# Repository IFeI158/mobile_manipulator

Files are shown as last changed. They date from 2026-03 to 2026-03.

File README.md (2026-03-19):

# Mobile Manipulator Robot (지능형 도우미 로봇)

거동이 불편한 사용자가 원격으로 물체를 지정하면, 지능형 도우미 로봇이 해당 물체를 스스로 찾아 집어 가져오는 시스템입니다.

모바일 플랫폼(TurtleBot3)과 직접 설계·제작한 4-DOF 로봇팔을 결합한 **Mobile Manipulator** 로, ArUco 마커 기반 비전과 역기구학(IK)을 통해 물체를 자율적으로 집어 초기 위치로 복귀합니다.

---

## Project Overview

| 항목 | 내용 |
|---|---|
| 기간 | 2025.03 – 2025.06 (1학기 캡스톤 디자인) |
| 인원 | 5명 |
| 역할 | Hardware 설계 / Vision 개발 |
| 플랫폼 | TurtleBot3 Burger + 직접 제작 로봇팔 |

---

## System Architecture

```
User ('p' key press)
        ↓
OAK-D Camera — ArUco Marker Detection
        ↓
3D Position Estimation (Stereo Depth + IQR Filter)
        ↓
Inverse Kinematics (ik_solver.py)
        ↓
Serial Command → Arduino (amurokena.ino)
        ↓
Servo Motion → Pick Object → Return to Home
```

---

## Repository Structure

```
mobile-manipulator/
├── vision/
│   ├── aruco_vision.py        ArUco 인식 + 3D 좌표 추출 (디버깅용)
│   └── color_vision.py        HSV 색상 인식 초기 버전 (참고용)
│
├── arm_control/
│   ├── main.py                메인 실행 파일 (ArUco + IK + 시리얼 통합)
│   ├── ik_solver.py           역기구학 계산 모듈
│   └── test_ik.py             터미널 수동 테스트용
│
├── arduino/
│   ├── amurokena/
│   │   └── amurokena.ino      최종 Arduino (moveAllSmooth + 자동 파지/복귀)
│   └── slow/
│       └── slow.ino           이전 버전 Arduino (참고용)
│
├── ros2_ws/
│   └── src/
│       ├── capstone_design_description/   URDF + STL 메시
│       └── capstone_design_config/        MoveIt2 설정
│
├── robotarm_capstone.xacro    로봇팔 XACRO 모델
└── README.md
```

---

## Hardware

| 부품 | 사양 |
|---|---|
| Mobile Platform | TurtleBot3 Burger |
| Controller | OpenCR 1.0 |
| Camera | Luxonis OAK-D (DepthAI) |
| LiDAR | YDLiDAR |
| Servo ×6 | MG996R / SG90 |
| MCU | Arduino Uno |

### Robot Arm Link Parameters

| Link | Length | Description |
|---|---|---|
| L1 | 20.404 cm | Shoulder → Elbow |
| L2 | 17.617 cm | Elbow → Wrist |
| L3 | 4.65 cm | Wrist → End-effector |
| BASE_Z_OFFSET | 7.8 cm | Base → first joint height |

### Arduino Pin Mapping

| Servo | Pin | Role |
|---|-----|---|
| servo0 | 12 | BASE yaw |
| servo1a | 11 | SHOULDER (forward) |
| servo1b | 10 | SHOULDER (reverse, 180 − s1) |
| servo2 | 9 | ELBOW |
| servo3 | 8 | WRIST |
| servo4 | 7 | GRIPPER |

---

## Software Stack

- **ROS2 (Humble)** — Navigation, TF, SLAM
- **Python 3** — Vision, IK, serial communication
- **DepthAI** — OAK-D stereo depth pipeline
- **OpenCV** — ArUco detection
- **Arduino** — Servo control

---

## Quick Start

### 1. Install dependencies

```bash
pip install depthai opencv-python numpy pyserial
```

### 2. Upload Arduino firmware

Open `arduino/amurokena/amurokena.ino` in Arduino IDE and upload to Arduino Uno.

### 3. Run main program

```bash
cd arm_control
python3 main.py
```

### 4. Key controls

| Key | Action |
|-----|---|
| `p` | Move arm to ArUco ID 9 marker position |
| `o` | Print ArUco ID 10 coordinates (debug) |
| `q` | Quit |

### 5. Manual IK test (without camera)

```bash
cd arm_control
python3 test_ik.py
# > 10 0 -5    (x y z in cm, camera frame)
```

---

## Serial Protocol

```
Python → Arduino : "s0,s1,s2,s3\n"         (4 angles, comma-separated)
Arduino → Python : "Received: s0,s1,s2,s3"  (debug echo)
Arduino → Python : "done"                    (pick-and-return complete)

Port  : /dev/ttyACM0
Baud  : 9600
```

---

## ArUco Marker IDs

| ID | Role |
|----|---|
| 9 | Target object — arm moves here on `p` key |
| 10 | Drop zone — coordinates printed on `o` key |

Dictionary: `DICT_4X4_50`

---

## Demonstration

> 시연 영상 추가 예정

---

## Future Improvements

- `hujin.py` — 물체 파지 후 Nav2를 통한 후진 복귀 로직 구현
- Object detection 기반 자동 마커 없는 물체 인식
- MoveIt2 기반 Motion Planning 통합
- SLAM 환경 인식 개선

---

## Author

**IFeI158** — Mechanical Engineering / Robotics & Autonomous Systems

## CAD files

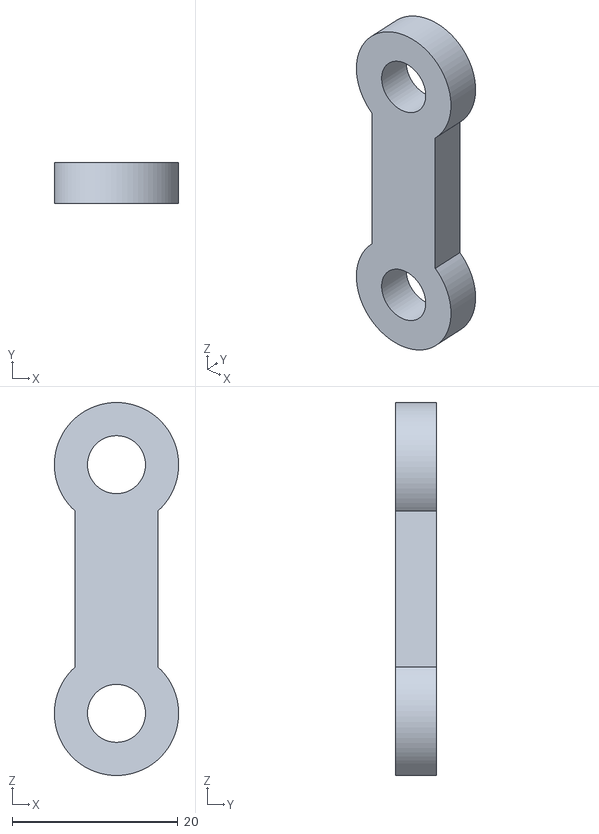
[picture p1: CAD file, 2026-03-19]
ros2_ws/src/capstone_design_description/meshes/left_gripper_link_1.stl
15.0 x 5.00 x 45.0

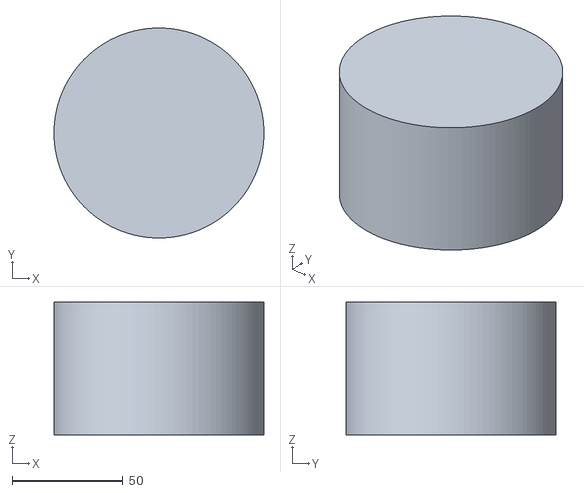
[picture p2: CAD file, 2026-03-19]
ros2_ws/src/capstone_design_description/meshes/lidar_1.stl
95.0 x 95.0 x 60.0

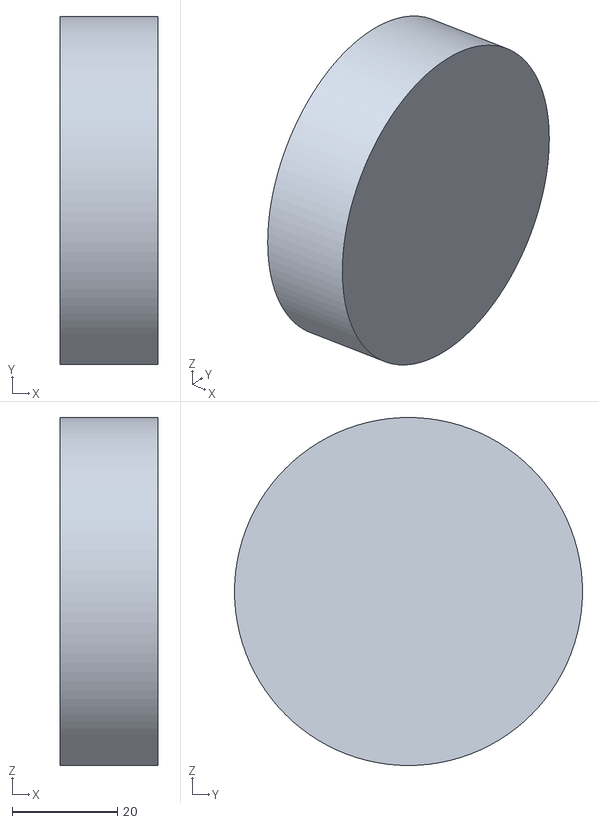
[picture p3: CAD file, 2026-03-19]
ros2_ws/src/capstone_design_description/meshes/right_wheel_1.stl
18.6 x 66.0 x 66.0

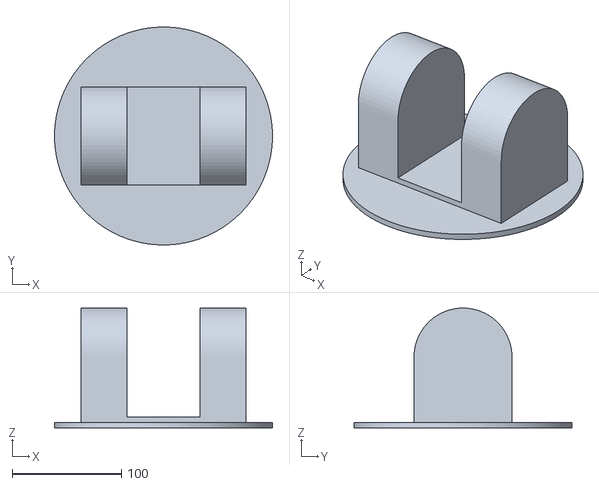
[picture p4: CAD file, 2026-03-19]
ros2_ws/src/capstone_design_description/meshes/link1_1.stl
200.0 x 199.9 x 110.0

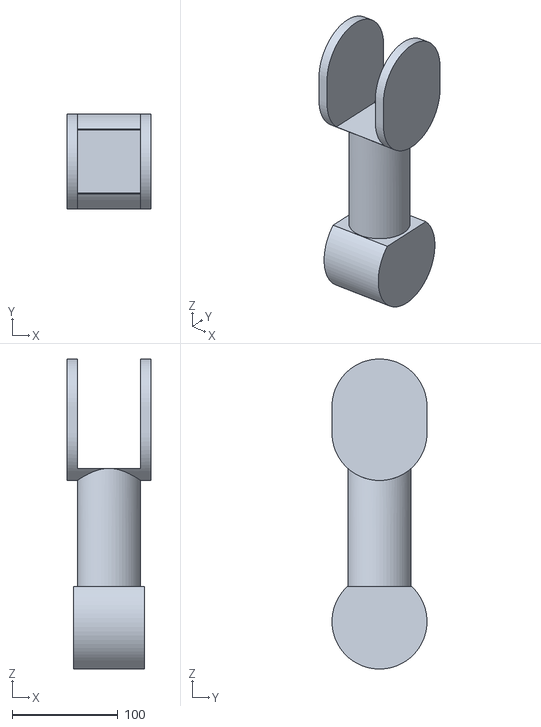
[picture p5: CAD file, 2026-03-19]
ros2_ws/src/capstone_design_description/meshes/link2_1.stl
80.0 x 90.0 x 293.5

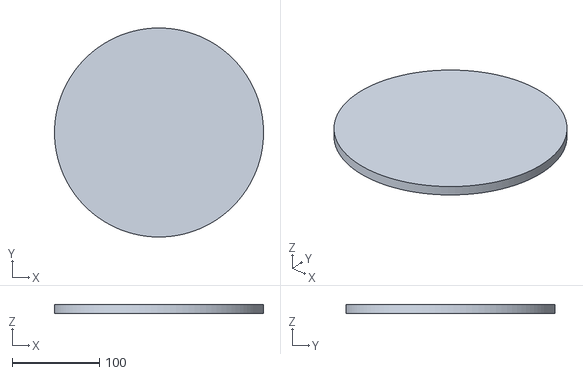
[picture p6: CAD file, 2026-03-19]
ros2_ws/src/capstone_design_description/meshes/arm_base_link_1.stl
239.9 x 240.0 x 10.0

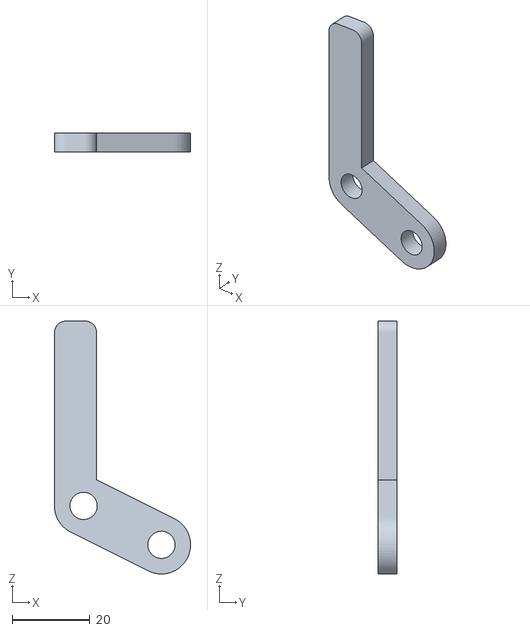
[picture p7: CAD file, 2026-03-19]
ros2_ws/src/capstone_design_description/meshes/right_finger_1.stl
35.0 x 5.00 x 65.0

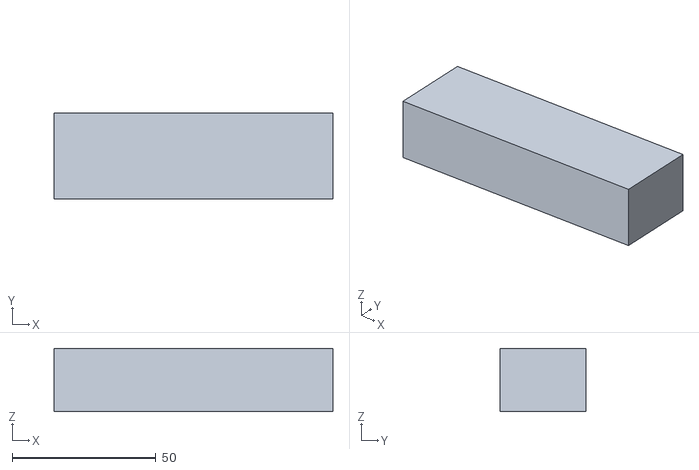
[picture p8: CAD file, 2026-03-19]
ros2_ws/src/capstone_design_description/meshes/stereo_camera_1.stl
97.0 x 30.0 x 22.0

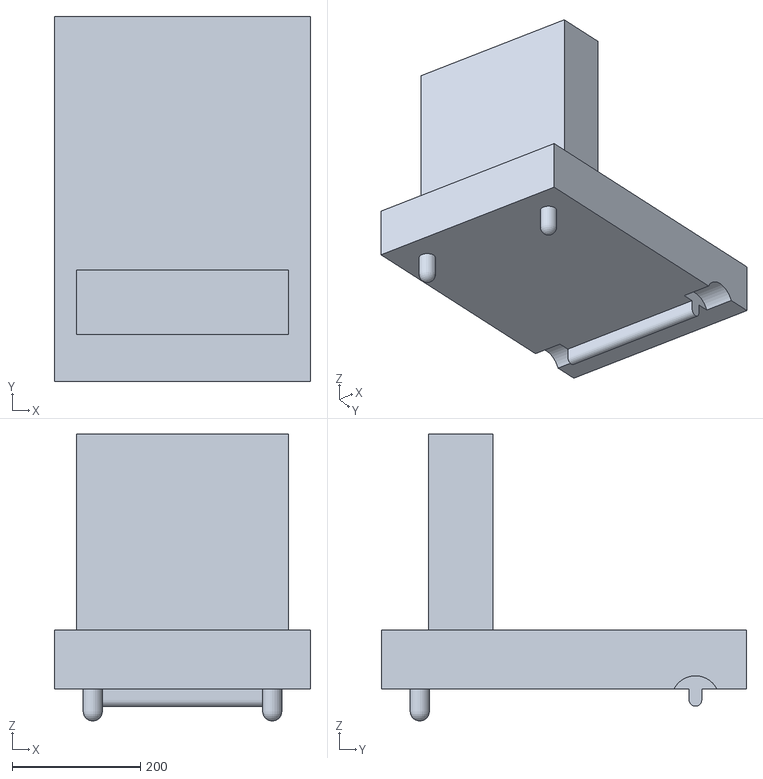
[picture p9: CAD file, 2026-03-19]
ros2_ws/src/capstone_design_description/meshes/base_link.stl
400.0 x 570.0 x 447.7

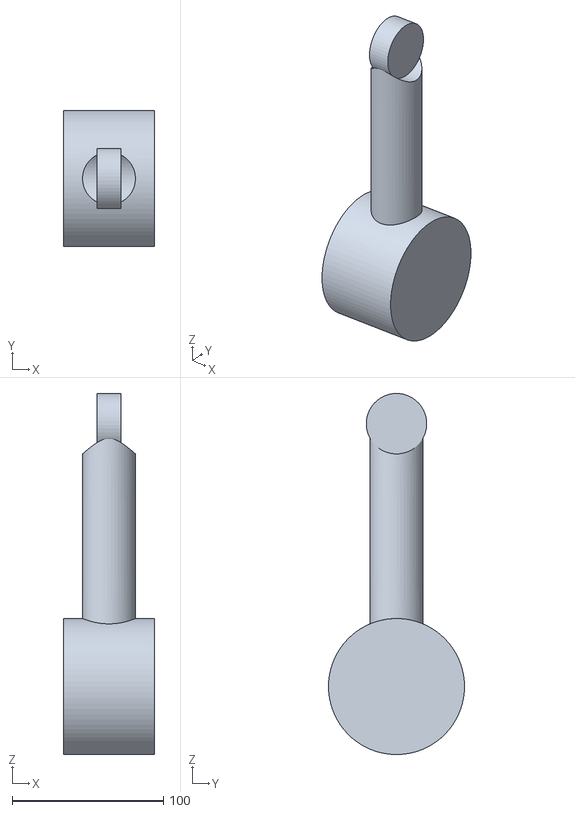
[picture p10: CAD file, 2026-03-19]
ros2_ws/src/capstone_design_description/meshes/link3_1.stl
60.0 x 90.0 x 238.8

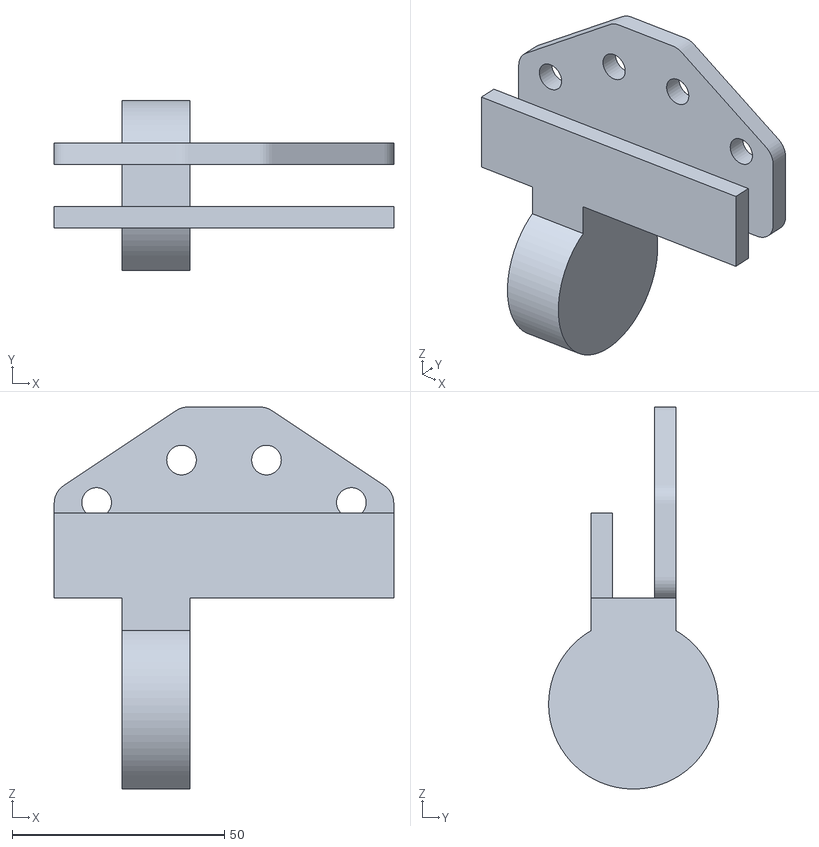
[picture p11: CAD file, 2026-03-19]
ros2_ws/src/capstone_design_description/meshes/hand_link_1.stl
80.0 x 40.0 x 90.0

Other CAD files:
ros2_ws/src/capstone_design_description/meshes/right_gripper_link_1.stl
ros2_ws/src/capstone_design_description/meshes/left_wheel_1.stl
ros2_ws/src/capstone_design_description/meshes/left_finger_1.stl

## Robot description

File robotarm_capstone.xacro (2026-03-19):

<?xml version="1.0" ?>
<robot name="robotarm_capstone" xmlns:xacro="http://www.ros.org/wiki/xacro">

<xacro:include filename="$(find robotarm_capstone_description)/urdf/materials.xacro" />
<xacro:include filename="$(find robotarm_capstone_description)/urdf/robotarm_capstone.trans" />
<xacro:include filename="$(find robotarm_capstone_description)/urdf/robotarm_capstone.gazebo" />
<link name="base_link">
  <inertial>
    <origin xyz="4.020849375084743e-17 0.0 0.005000000000000001" rpy="0 0 0"/>
    <mass value="3.551256335617901"/>
    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
  </inertial>
  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
</link>

<link name="link1_1">
  <inertial>
    <origin xyz="2.0030450291854913e-17 2.0030450291854907e-17 0.04290880959465924" rpy="0 0 0"/>
    <mass value="7.128679889758317"/>
    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
  </inertial>
  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
</link>

<link name="link2_1">
  <inertial>
    <origin xyz="0.03360000772838613 -8.485027970501936e-11 0.06805286707917997" rpy="0 0 0"/>
    <mass value="6.954595389355063"/>
    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
  </inertial>
  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
</link>

<link name="link3_1">
  <inertial>
    <origin xyz="0.030000023541393757 4.114813245135107e-18 0.02802505675959771" rpy="0 0 0"/>
    <mass value="3.999606826289236"/>
    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
  </inertial>
  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
</link>

<link name="hand_link_1">
  <inertial>
    <origin xyz="-0.0017307714096714746 0.0029387009017803663 0.018364409381455116" rpy="0 0 0"/>
    <mass value="0.28375707869235817"/>
    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
  </inertial>
  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
</link>

<link name="right_gripper_link1_1">
  <inertial>
    <origin xyz="-6.42194630806614e-14 -0.002499999999999998 0.014999999999971148" rpy="0 0 0"/>
    <mass value="0.01720971564055042"/>
    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
  </inertial>
  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
</link>

<link name="right_gripper_link2_1">
  <inertial>
    <origin xyz="-6.4248953379753e-14 -0.002499999999999998 0.014999999999971148" rpy="0 0 0"/>
    <mass value="0.017209715640550204"/>
    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
  </inertial>
  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
</link>

<link name="left_gripper_link2_1">
  <inertial>
    <origin xyz="-6.424548393280105e-14 -0.002499999999999998 0.014999999999971037" rpy="0 0 0"/>
    <mass value="0.0172097156405502"/>
    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
  </inertial>
  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
</link>

<link name="left_gripper_link1_1">
  <inertial>
    <origin xyz="-6.42715047849407e-14 -0.002499999999999998 0.014999999999970925" rpy="0 0 0"/>
    <mass value="0.01720971564055051"/>
    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
  </inertial>
  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
</link>

<link name="right_finger_1">
  <inertial>
    <origin xyz="-0.0038609530597631878 -0.002499999999999998 0.010996703413204356" rpy="0 0 0"/>
    <mass value="0.03447696599229279"/>
    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
  </inertial>
  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
</link>

<link name="left_finger_1">
  <inertial>
    <origin xyz="-0.01613904694030094 -0.002499999999999998 0.020996703413204365" rpy="0 0 0"/>
    <mass value="0.034476965992292836"/>
    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
  </inertial>
  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
</link>

<joint name="base_link_to_link1" type="revolute">
  <origin xyz="0.0 0.0 0.01" rpy="0 0 0"/>
  <parent link="base_link"/>
  <child link="link1_1"/>
  <axis xyz="0.0 0.0 1.0"/>
  <limit upper="1.570796" lower="-1.570796" effort="100" velocity="100"/>
</joint>

<joint name="link1_to_link2" type="revolute">
  <origin xyz="-0.0336 0.0 0.065" rpy="0 0 0"/>
  <parent link="link1_1"/>
  <child link="link2_1"/>
  <axis xyz="-1.0 0.0 0.0"/>
  <limit upper="1.570796" lower="-1.570796" effort="100" velocity="100"/>
</joint>

<joint name="link2_to_link3" type="revolute">
  <origin xyz="0.0036 0.0 0.203557" rpy="0 0 0"/>
  <parent link="link2_1"/>
  <child link="link3_1"/>
  <axis xyz="-1.0 0.0 0.0"/>
  <limit upper="1.570796" lower="-1.570796" effort="100" velocity="100"/>
</joint>

<joint name="link3_to_hand_link" type="revolute">
  <origin xyz="0.022 0.0 0.1739" rpy="0 0 0"/>
  <parent link="link3_1"/>
  <child link="hand_link_1"/>
  <axis xyz="-1.0 0.0 0.0"/>
  <limit upper="1.570796" lower="-1.570796" effort="100" velocity="100"/>
</joint>

<joint name="hand_link_to_left_gripper_link2" type="revolute">
  <origin xyz="0.018 0.005 0.0575" rpy="0 0 0"/>
  <parent link="hand_link_1"/>
  <child link="left_gripper_link2_1"/>
  <axis xyz="0.0 1.0 -0.0"/>
  <limit upper="1.22173" lower="0.0" effort="100" velocity="100"/>
</joint>

<joint name="hand_link_to_left_gripper_link1" type="revolute">
  <origin xyz="0.038 0.005 0.0475" rpy="0 0 0"/>
  <parent link="hand_link_1"/>
  <child link="left_gripper_link1_1"/>
  <axis xyz="0.0 1.0 -0.0"/>
  <mimic joint="hand_link_to_left_gripper_link2" multiplier="1.0" offset="0.0"/>
  <limit upper="1.22173" lower="0.0" effort="100" velocity="100"/>
</joint>

<joint name="left_gripper_link1_to_left_finger" type="revolute">
  <origin xyz="0.0 -0.005 0.03" rpy="0 0 0"/>
  <parent link="left_gripper_link1_1"/>
  <child link="left_finger_1"/>
  <axis xyz="0.0 1.0 -0.0"/>
  <mimic joint="hand_link_to_left_gripper_link2" multiplier="-1.0" offset="0.0"/>
  <limit upper="0.0" lower="-1.22173" effort="100" velocity="100"/>
</joint>

<joint name="left_gripper_link2_to_left_finger" type="revolute">
  <origin xyz="0.02 -0.005 0.02" rpy="0 0 0"/>
  <parent link="left_gripper_link2_1"/>
  <child link="left_finger_1"/>
  <axis xyz="0.0 1.0 -0.0"/>
  <mimic joint="hand_link_to_left_gripper_link2" multiplier="-1.0" offset="0.0"/>
  <limit upper="0.0" lower="-1.22173" effort="100" velocity="100"/>
</joint>

<joint name="hand_link_to_right_gripper_link1" type="revolute">
  <origin xyz="-0.022 0.005 0.0475" rpy="0 0 0"/>
  <parent link="hand_link_1"/>
  <child link="right_gripper_link1_1"/>
  <axis xyz="0.0 1.0 -0.0"/>
  <limit upper="0.0" lower="-1.22173" effort="100" velocity="100"/>
</joint>

<joint name="hand_link_to_right_gripper_link2" type="revolute">
  <origin xyz="-0.002 0.005 0.0575" rpy="0 0 0"/>
  <parent link="hand_link_1"/>
  <child link="right_gripper_link2_1"/>
  <axis xyz="0.0 1.0 -0.0"/>
  <mimic joint="hand_link_to_right_gripper_link1" multiplier="-1.0" offset="0.0"/>
  <limit upper="0.0" lower="-1.22173" effort="100" velocity="100"/>
</joint>

<joint name="right_gripper_link1_to_right_finger" type="revolute">
  <origin xyz="0.02 -0.005 0.04" rpy="0 0 0"/>
  <parent link="right_gripper_link1_1"/>
  <child link="right_finger_1"/>
  <axis xyz="-0.0 1.0 -0.0"/>
  <mimic joint="hand_link_to_right_gripper_link1" multiplier="1.0" offset="0.0"/>
  <limit upper="1.22173" lower="0.0" effort="100" velocity="100"/>
</joint>

<joint name="right_gripper_link2_to_right_finger" type="revolute">
  <origin xyz="0.0 -0.005 0.03" rpy="0 0 0"/>
  <parent link="right_gripper_link2_1"/>
  <child link="right_finger_1"/>
  <axis xyz="-0.0 1.0 -0.0"/>
  <mimic joint="hand_link_to_right_gripper_link1" multiplier="1.0" offset="0.0"/>
  <limit upper="1.22173" lower="0.0" effort="100" velocity="100"/>
</joint>

</robot>

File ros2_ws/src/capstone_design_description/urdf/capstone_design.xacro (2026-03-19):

<?xml version="1.0" ?>
<robot name="capstone_design" xmlns:xacro="http://www.ros.org/wiki/xacro">

<xacro:include filename="$(find capstone_design_description)/urdf/materials.xacro" />
<xacro:include filename="$(find capstone_design_description)/urdf/capstone_design.trans" />
<xacro:include filename="$(find capstone_design_description)/urdf/capstone_design.gazebo" />
<link name="base_link">
  <inertial>
    <origin xyz="0.0 -0.18760221512473715 0.11026773981655406" rpy="0 0 0"/>
    <mass value="244.42049863775813"/>
    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
  </inertial>
  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
</link>

<link name="arm_base_link_1">
  <inertial>
    <origin xyz="4.020849375084743e-17 0.0 0.0049999999999999906" rpy="0 0 0"/>
    <mass value="3.551256335617901"/>
    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
  </inertial>
  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
</link>

<link name="link1_1">
  <inertial>
    <origin xyz="2.0030450291854913e-17 2.0030450291854907e-17 0.04290880959465923" rpy="0 0 0"/>
    <mass value="7.128679889758317"/>
    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
  </inertial>
  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
</link>

<link name="link2_1">
  <inertial>
    <origin xyz="0.03360000772838613 -8.485027970501936e-11 0.06805286707917996" rpy="0 0 0"/>
    <mass value="6.954595389355063"/>
    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
  </inertial>
  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
</link>

<link name="link3_1">
  <inertial>
    <origin xyz="0.030000023541393757 4.114813245135107e-18 0.02802505675959771" rpy="0 0 0"/>
    <mass value="3.999606826289236"/>
    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
  </inertial>
  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
</link>

<link name="hand_link_1">
  <inertial>
    <origin xyz="3.255267775751497e-05 0.0010470921107968664 0.021378963563369324" rpy="0 0 0"/>
    <mass value="0.34655707869237173"/>
    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
  </inertial>
  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
</link>

<link name="left_gripper_link_1">
  <inertial>
    <origin xyz="-6.42194630806614e-14 -0.002499999999999998 0.014999999999971148" rpy="0 0 0"/>
    <mass value="0.01720971564055042"/>
    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
  </inertial>
  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
</link>

<link name="right_gripper_link_1">
  <inertial>
    <origin xyz="-6.42715047849407e-14 -0.002499999999999998 0.014999999999970925" rpy="0 0 0"/>
    <mass value="0.01720971564055051"/>
    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
  </inertial>
  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
</link>

<link name="left_finger_1">
  <inertial>
    <origin xyz="0.01613904694023681 -0.002499999999999998 0.020996703413204365" rpy="0 0 0"/>
    <mass value="0.03447696599229279"/>
    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
  </inertial>
  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
</link>

<link name="right_finger_1">
  <inertial>
    <origin xyz="-0.01613904694030094 -0.002499999999999998 0.020996703413204365" rpy="0 0 0"/>
    <mass value="0.034476965992292836"/>
    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
  </inertial>
  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
</link>

<link name="right_wheel_1">
  <inertial>
    <origin xyz="0.009299999999999975 -1.3877787807814457e-17 3.469446951953614e-18" rpy="0 0 0"/>
    <mass value="0.49952859430885366"/>
    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
  </inertial>
  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
</link>

<link name="left_wheel_1">
  <inertial>
    <origin xyz="-0.009300000000000003 0.0 -1.0408340855860843e-17" rpy="0 0 0"/>
    <mass value="0.4995285943088536"/>
    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
  </inertial>
  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
</link>

<link name="lidar_1">
  <inertial>
    <origin xyz="1.06925634351284e-17 -5.551115123125783e-17 0.030000000000000027" rpy="0 0 0"/>
    <mass value="3.3385508780157878"/>
    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
  </inertial>
  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
</link>

<link name="stereo_camera_1">
  <inertial>
    <origin xyz="0.0 -0.01499999999999999 2.5403783909805355e-07" rpy="0 0 0"/>
    <mass value="0.5025570000000006"/>
    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
  </inertial>
  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
</link>

<joint name="base_link_to_arm_base_link" type="revolute">
  <origin xyz="0.0 0.0 0.0918" rpy="0 0 0"/>
  <parent link="base_link"/>
  <child link="arm_base_link_1"/>
  <axis xyz="0.0 0.0 1.0"/>
  <limit upper="1.570796" lower="-1.570796" effort="100" velocity="100"/>
</joint>

<joint name="arm_base_link_to_link1" type="fixed">
  <origin xyz="0.0 0.0 0.01" rpy="0 0 0"/>
  <parent link="arm_base_link_1"/>
  <child link="link1_1"/>
</joint>

<joint name="link1_to_link2" type="revolute">
  <origin xyz="-0.0336 0.0 0.065" rpy="0 0 0"/>
  <parent link="link1_1"/>
  <child link="link2_1"/>
  <axis xyz="-1.0 0.0 0.0"/>
  <limit upper="1.570796" lower="-1.570796" effort="100" velocity="100"/>
</joint>

<joint name="link2_to_link3" type="revolute">
  <origin xyz="0.0036 0.0 0.203557" rpy="0 0 0"/>
  <parent link="link2_1"/>
  <child link="link3_1"/>
  <axis xyz="-1.0 0.0 0.0"/>
  <limit upper="1.570796" lower="-1.570796" effort="100" velocity="100"/>
</joint>

<joint name="link3_to_hand_link" type="revolute">
  <origin xyz="0.022 0.0 0.1739" rpy="0 0 0"/>
  <parent link="link3_1"/>
  <child link="hand_link_1"/>
  <axis xyz="-1.0 0.0 0.0"/>
  <limit upper="1.570796" lower="-1.570796" effort="100" velocity="100"/>
</joint>

<joint name="hand_link_to_left_gripper_link" type="revolute">
  <origin xyz="-0.022 0.005 0.0475" rpy="0 0 0"/>
  <parent link="hand_link_1"/>
  <child link="left_gripper_link_1"/>
  <axis xyz="0.0 1.0 -0.0"/>
  <limit upper="0.0" lower="-1.22173" effort="100" velocity="100"/>
</joint>

<joint name="hand_link_to_right_gripper_link" type="revolute">
  <origin xyz="0.038 0.005 0.0475" rpy="0 0 0"/>
  <parent link="hand_link_1"/>
  <child link="right_gripper_link_1"/>
  <axis xyz="0.0 1.0 -0.0"/>
  <mimic joint="hand_link_to_left_gripper_link" multiplier="-1.0" offset="0.0"/>
  <limit upper="1.22173" lower="0.0" effort="100" velocity="100"/>
</joint>
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

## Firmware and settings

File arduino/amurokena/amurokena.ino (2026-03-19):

/**
 * amurokena.ino — Robot arm servo controller (final version)
 *
 * Receives servo angles from Python via serial (format: "s0,s1,s2,s3\n"),
 * moves all joints smoothly to the target, closes the gripper to pick
 * an object, lifts link-2, then returns to the home pose.
 *
 * Serial protocol
 * ---------------
 *   Python → Arduino : "s0,s1,s2,s3\n"   (4 angles, comma-separated)
 *   Arduino → Python : "Received: s0,s1,s2,s3\n"
 *   Arduino → Python : "done\n"           (after pick-and-return completes)
 *
 * Pin mapping
 * -----------
 *   pin 12  servo0  — BASE yaw
 *   pin 11  servo1a — SHOULDER (forward)
 *   pin 10  servo1b — SHOULDER (reverse, writes 180 - s1)
 *   pin  9  servo2  — ELBOW
 *   pin  8  servo3  — WRIST
 *   pin  7  servo4  — GRIPPER
 */

#include <Servo.h>

// ── Servo objects ─────────────────────────────────────────────────────────────
Servo servo0;   // Base
Servo servo1a;  // Shoulder (forward)
Servo servo1b;  // Shoulder (reverse)
Servo servo2;   // Elbow
Servo servo3;   // Wrist
Servo servo4;   // Gripper

// ── Pin assignments ───────────────────────────────────────────────────────────
const int PIN_BASE      = 12;
const int PIN_SHOULDER_A = 11;
const int PIN_SHOULDER_B = 10;
const int PIN_ELBOW     =  9;
const int PIN_WRIST     =  8;
const int PIN_GRIPPER   =  7;

// ── Home pose angles (degrees) ────────────────────────────────────────────────
const int INIT_S0 = 90;
const int INIT_S1 = 130;
const int INIT_S2 = 0;
const int INIT_S3 = 130;

// ── Gripper angles ────────────────────────────────────────────────────────────
const int GRIPPER_OPEN   = 120;
const int GRIPPER_CLOSED = 60;

// ── Motion timing (ms per step) ───────────────────────────────────────────────
const int SMOOTH_DELAY   = 40;   // Normal joint step delay
const int ELBOW_DELAY    = 20;   // Elbow moves at 2× speed


// ── Utility ───────────────────────────────────────────────────────────────────
int clamp(int val, int minVal, int maxVal) {
  return max(minVal, min(maxVal, val));
}

/** Move a single servo smoothly to target. */
void moveSmooth(Servo &sv, int target, int delayMs = SMOOTH_DELAY) {
  int curr = sv.read();
  int dir  = (target > curr) ? 1 : -1;
  for (int p = curr; p != target; p += dir) {
    sv.write(p);
    delay(delayMs);
  }
  sv.write(target);
}

/**
 * Move base first (yaw), then shoulder / elbow / wrist simultaneously.
 * Elbow runs at double speed via a separate timer.
 */
void moveAllSmooth(int v0, int v1, int v2, int v3) {
  // 1. Base yaw
  moveSmooth(servo0, v0, SMOOTH_DELAY);

  // 2. Shoulder + elbow + wrist in parallel
  int curr1 = servo1a.read();
  int curr2 = servo2.read();
  int curr3 = servo3.read();
  int maxStep = max({ abs(v1 - curr1), abs(v2 - curr2), abs(v3 - curr3) });

  int dir2 = (v2 > curr2) ? 1 : -1;
  int stepCount2 = 0;
  unsigned long lastElbowTime = millis();

  for (int i = 0; i <= maxStep; i++) {
    if (i <= abs(v1 - curr1)) {
      int pos = curr1 + (v1 > curr1 ? i : -i);
      servo1a.write(pos);
      servo1b.write(180 - pos);
    }
    if (i <= abs(v3 - curr3)) {
      servo3.write(curr3 + (v3 > curr3 ? i : -i));
    }
    // Elbow at double speed
    if (stepCount2 <= abs(v2 - curr2) &&
        millis() - lastElbowTime >= ELBOW_DELAY) {
      servo2.write(curr2 + dir2 * stepCount2);
      stepCount2++;
      lastElbowTime = millis();
    }
    delay(SMOOTH_DELAY);
  }
}

/** Full pick-and-return sequence after reaching target pose. */
void pickAndReturn() {
  // Close gripper
  servo4.write(GRIPPER_CLOSED);
  delay(1000);

  // Lift elbow slightly
  int lifted_s2 = clamp(servo2.read() + 20, 0, 180);
  moveSmooth(servo2, lifted_s2, SMOOTH_DELAY);

  // Partial shoulder retract (1 second worth)
  {
    int curr1    = servo1a.read();
    int diff1    = INIT_S1 - curr1;
    int dir1     = (diff1 > 0) ? 1 : -1;
    int maxSteps = min(abs(diff1), 1000 / SMOOTH_DELAY);
    for (int i = 1; i <= maxSteps; i++) {
      int pos = curr1 + dir1 * i;
      servo1a.write(pos);
      servo1b.write(180 - pos);
      delay(SMOOTH_DELAY);
    }
    int elapsed = maxSteps * SMOOTH_DELAY;
    if (elapsed < 1000) delay(1000 - elapsed);
  }

  // Return to home pose
  moveAllSmooth(INIT_S0, INIT_S1, INIT_S2, INIT_S3);
}


// ── Setup ─────────────────────────────────────────────────────────────────────
void setup() {
  Serial.begin(9600);

  // Write before attach to prevent servo twitch on power-up
  servo0.write(INIT_S0);
  servo1a.write(INIT_S1);
  servo1b.write(180 - INIT_S1);
  servo2.write(INIT_S2);
  servo3.write(INIT_S3);
  servo4.write(GRIPPER_OPEN);

  servo0.attach(PIN_BASE);
  servo1a.attach(PIN_SHOULDER_A);
  servo1b.attach(PIN_SHOULDER_B);
  servo2.attach(PIN_ELBOW);
  servo3.attach(PIN_WRIST);
  servo4.attach(PIN_GRIPPER);

  delay(300);

  // Smooth move to home pose
  moveSmooth(servo0, INIT_S0);
  moveSmooth(servo1a, INIT_S1);
  moveSmooth(servo1b, 180 - INIT_S1);
  moveSmooth(servo2, INIT_S2);
  moveSmooth(servo3, INIT_S3);
}


// ── Loop ──────────────────────────────────────────────────────────────────────
void loop() {
  if (!Serial.available()) return;

  // Parse "s0,s1,s2,s3\n"
  String line = Serial.readStringUntil('\n');
  int vals[4] = { INIT_S0, INIT_S1, INIT_S2, INIT_S3 };
  int idx = 0, start = 0;
  for (int i = 0; i <= (int)line.length(); i++) {
    if (i == (int)line.length() || line.charAt(i) == ',') {
      vals[idx++] = line.substring(start, i).toInt();
      start = i + 1;
      if (idx >= 4) break;
    }
  }

  // Echo for debugging
  Serial.print("Received: ");
  for (int i = 0; i < 4; i++) {
    Serial.print(vals[i]);
    Serial.print(i < 3 ? "," : "\n");
  }

  // Move to target, then pick and return
  moveAllSmooth(vals[0], vals[1], vals[2], vals[3]);
  delay(1000);
  pickAndReturn();

  Serial.println("done");
}

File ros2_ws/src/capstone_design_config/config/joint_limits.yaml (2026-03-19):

# joint_limits.yaml allows the dynamics properties specified in the URDF to be overwritten or augmented as needed

# For beginners, we downscale velocity and acceleration limits.
# You can always specify higher scaling factors (<= 1.0) in your motion requests.  # Increase the values below to 1.0 to always move at maximum speed.
default_velocity_scaling_factor: 0.1
default_acceleration_scaling_factor: 0.1

# Specific joint properties can be changed with the keys [max_position, min_position, max_velocity, max_acceleration]
# Joint limits can be turned off with [has_velocity_limits, has_acceleration_limits]
joint_limits:
  base_link_to_arm_base_link:
    has_velocity_limits: true
    max_velocity: 100.0
    has_acceleration_limits: false
    max_acceleration: 0.0
  hand_link_to_left_gripper_link:
    has_velocity_limits: true
    max_velocity: 100.0
    has_acceleration_limits: false
    max_acceleration: 0.0
  hand_link_to_right_gripper_link:
    has_velocity_limits: true
    max_velocity: 100.0
    has_acceleration_limits: false
    max_acceleration: 0.0
  left_gripper_link_to_left_finger:
    has_velocity_limits: true
    max_velocity: 100.0
    has_acceleration_limits: false
    max_acceleration: 0.0
  link1_to_link2:
    has_velocity_limits: true
    max_velocity: 100.0
    has_acceleration_limits: false
    max_acceleration: 0.0
  link2_to_link3:
    has_velocity_limits: true
    max_velocity: 100.0
    has_acceleration_limits: false
    max_acceleration: 0.0
  link3_to_hand_link:
    has_velocity_limits: true
    max_velocity: 100.0
    has_acceleration_limits: false
    max_acceleration: 0.0
  right_gripper_link_to_right_finger:
    has_velocity_limits: true
    max_velocity: 100.0
    has_acceleration_limits: false
    max_acceleration: 0.0

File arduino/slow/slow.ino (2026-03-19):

#include <Servo.h>

// 서보 객체 정의
Servo servo0;       // 베이스
Servo servo1a;      // 1번 링크 (정방향)
Servo servo1b;      // 1번 링크 (역방향)
Servo servo2;       // 2번 링크
Servo servo3;       // 3번 링크
Servo servo4;       // 그리퍼

// 핀 번호 매핑
const int pin0  = 12;
const int pin1a = 11;
const int pin1b = 10;
const int pin2  = 9;
const int pin3  = 8;
const int pin4  = 7;

// 초기 각도 정의
const int INIT_S0 = 90;
const int INIT_S1 = 130;
const int INIT_S2 = 0;
const int INIT_S3 = 130;

// === 유틸 함수 ===
int clamp(int val, int minVal, int maxVal) {
  return max(minVal, min(val, maxVal));
}

void moveSmooth(Servo &sv, int target, int delayMs = 40) {
  int curr = sv.read();
  if (curr < target) {
    for (int p = curr; p <= target; p++) {
      sv.write(p);
      delay(delayMs);
    }
  } else {
    for (int p = curr; p >= target; p--) {
      sv.write(p);
      delay(delayMs);
    }
  }
}

void moveAllSmooth(int v0, int v1, int v2, int v3) {
  // 1. servo0 먼저 천천히 이동
  int curr0 = servo0.read();
  int step0 = abs(v0 - curr0);
  for (int i = 0; i <= step0; i++) {
    int pos = curr0 + (v0 > curr0 ? i : -i);
    servo0.write(pos);
    delay(40);
  }

  // 2. 나머지 동시에 부드럽게 이동
  int curr1 = servo1a.read();
  int curr2 = servo2.read();
  int curr3 = servo3.read();
  int maxStep = max(max(abs(v1 - curr1), abs(v2 - curr2)), abs(v3 - curr3));

  for (int i = 0; i <= maxStep; i++) {
    if (i <= abs(v1 - curr1)) {
      int step = curr1 + (v1 > curr1 ? i : -i);
      servo1a.write(step);
      servo1b.write(180 - step);
    }
    if (i <= abs(v2 - curr2)) {
      int pos = curr2 + (v2 > curr2 ? i : -i);
      servo2.write(pos);
    }
    if (i <= abs(v3 - curr3)) {
      int pos = curr3 + (v3 > curr3 ? i : -i);
      servo3.write(pos);
    }
    delay(40);
  }
}

void setup() {
  Serial.begin(9600);

  // ✴️ 튐 방지: 먼저 write
  servo0.write(INIT_S0);
  servo1a.write(INIT_S1);
  servo1b.write(180 - INIT_S1);
  servo2.write(INIT_S2);
  servo3.write(INIT_S3);
  servo4.write(180);  // 그리퍼 열림

  // ✴️ 그 후 attach
  servo0.attach(pin0);
  servo1a.attach(pin1a);
  servo1b.attach(pin1b);
  servo2.attach(pin2);
  servo3.attach(pin3);
  servo4.attach(pin4);

  delay(300);  // 초기 안정화

  // ✴️ 부드럽게 초기 위치로 복귀
  moveSmooth(servo0, INIT_S0, 40);
  moveSmooth(servo1a, INIT_S1, 40);
  moveSmooth(servo1b, 180 - INIT_S1, 40);
  moveSmooth(servo2, INIT_S2, 40);
  moveSmooth(servo3, INIT_S3, 40);
}

void loop() {
  if (!Serial.available()) return;

  String line = Serial.readStringUntil('\n');
  int vals[4] = {INIT_S0, INIT_S1, INIT_S2, INIT_S3};
  int idx = 0, start = 0;

  for (int i = 0; i <= line.length(); i++) {
    if (i == line.length() || line.charAt(i) == ',') {
      vals[idx++] = line.substring(start, i).toInt();
      start = i + 1;
      if (idx >= 4) break;
    }
  }

  // 디버깅 출력
  Serial.print("Received: ");
  for (int i = 0; i < 4; i++) {
    Serial.print(vals[i]);
    Serial.print(i < 3 ? "," : "\n");
  }

  // 1. 받은 각도로 이동 (베이스 먼저 → 나머지 동시에)
  moveAllSmooth(vals[0], vals[1], vals[2], vals[3]);

  // 2. 그리퍼 닫기
  delay(1000);
  moveSmooth(servo4, 50, 15);  // 그리퍼는 빠르게 닫기

  // 3. 링크2 (servo2) 20도 올리기
  int curr_s2 = servo2.read();
  int new_s2 = clamp(curr_s2 + 20, 0, 180);
  moveSmooth(servo2, new_s2, 40);

  // 4. 초기 위치로 복귀
  delay(1000);
  moveAllSmooth(INIT_S0, INIT_S1, INIT_S2, INIT_S3);
}
